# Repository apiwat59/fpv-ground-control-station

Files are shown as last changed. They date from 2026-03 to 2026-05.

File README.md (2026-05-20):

# Ground Control Station 'HALYT'

Ground Control Station 'HALYT' สำหรับ FPV drones เป็น modular system ที่รองรับการเปลี่ยน configuration ตามความเหมาะสมของงานและเงื่อนไขในการทำงาน

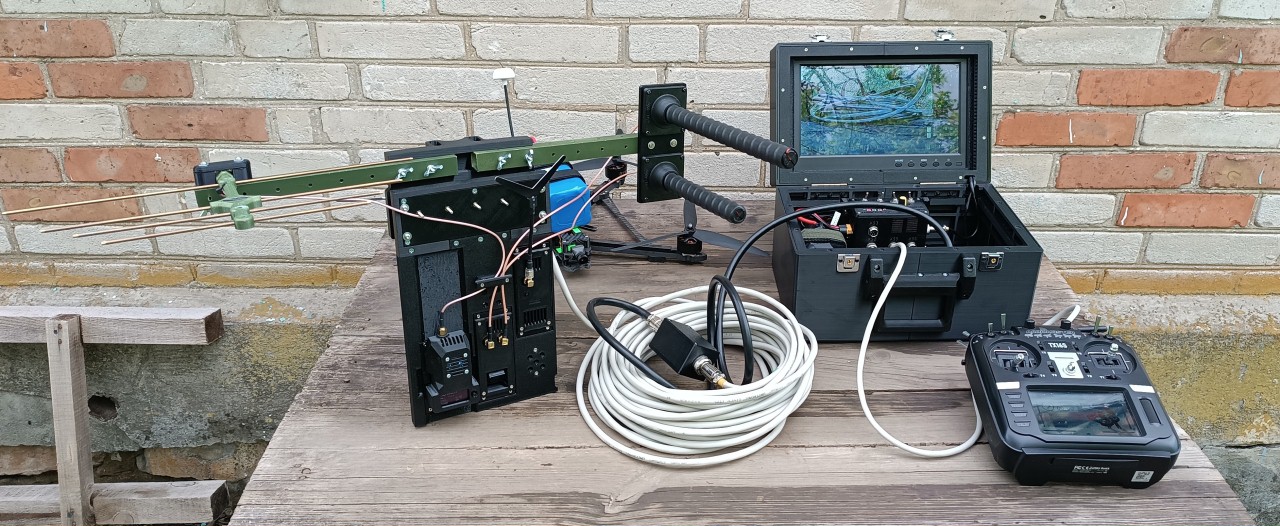
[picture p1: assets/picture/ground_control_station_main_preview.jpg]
General view of GCS 'HALYT'


สถาปัตยกรรมของสถานีตั้งอยู่บนหลักการของการแยกส่วนการทำงานของ system components ออกจากกัน และอนุญาตให้เพิ่ม functional expansion ได้โดยการรวม modules เพิ่มเติมโดยไม่ต้องเปลี่ยนโครงสร้างพื้นฐาน

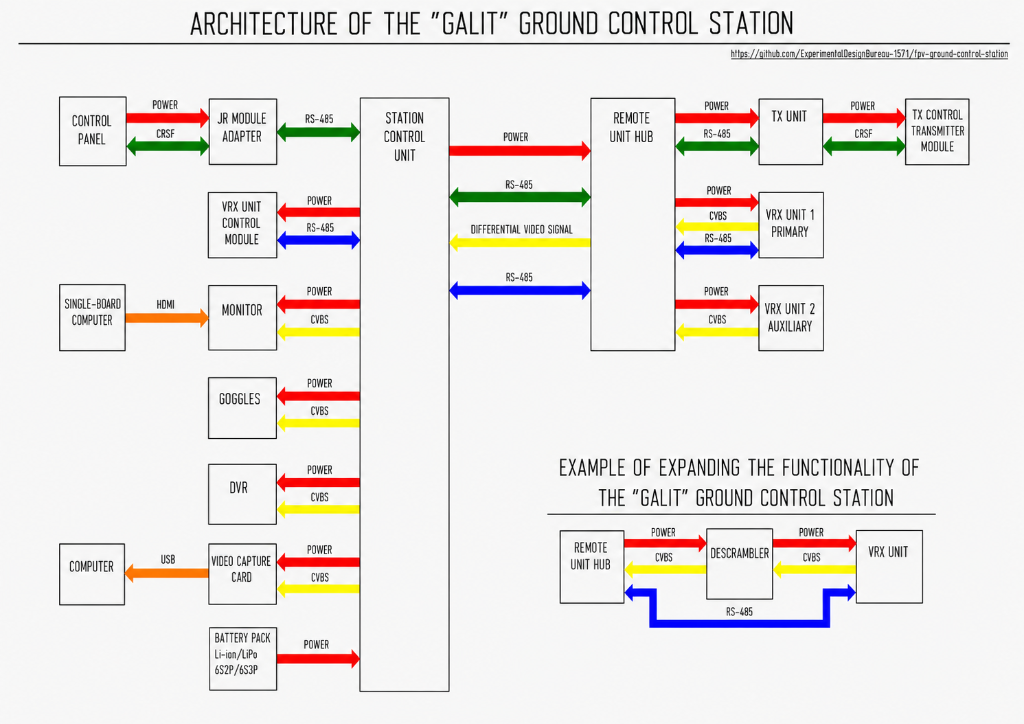
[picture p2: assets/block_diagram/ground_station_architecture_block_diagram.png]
GCS 'HALYT' Architecture


ระบบนี้ได้รับการพัฒนาขึ้นโดยคำนึงถึงประสบการณ์การรบจริงของเรา, ความพร้อมใช้งานของ components, การสนับสนุนผู้ผลิตในประเทศอย่างสูงสุด และความเป็นไปได้สำหรับเจ้าหน้าที่ด้านเทคนิคในการทำซ้ำแบบในโรงเวิร์กชอปภาคสนามทางการทหาร พลเรือน หรืออาสาสมัครที่มีอุปกรณ์ระดับปานกลาง

แนะนำให้ทำตามลำดับขั้นตอนด้านล่างนี้สำหรับการผลิตและการประกอบระบบ:

1.	**[Universal case and station body](Universal_case_and_station_body/)**
2.	**[Station control unit](Station_control_unit/)**
3.	**[Monitor modernization](Monitor_modernization/)**
4.	**[Remote unit](Remote_unit/)**
5.	**[VRX blocks](VRX_blocks/)**
6.	**[Control_subsystem](Control_subsystem/)**
7.	**[Cables](Cables/)**

## Video Guide for Manufacturing and Assembling GCS 'HALYT'

GCS HALYT — Full assembly video guide (https://www.youtube.com/watch?v=9ohl-sQVgZU)

*คลิกที่รูปภาพเพื่อรับชมวิดีโอบน YouTube*

เมื่อปฏิบัติตามคู่มือการผลิตและขั้นตอนปฏิบัติในการทำงาน ผลิตภัณฑ์ที่สมบูรณ์จะให้ระดับความแข็งแรงทางกล (mechanical strength), maintainability และคุณลักษณะการทำงานที่เทียบได้กับรุ่นที่ผลิตเพื่อการพาณิชย์ในคลาสเดียวกัน ภาพรวมทั่วไปของ Ground Control Station 'HALYT' แสดงอยู่ในภาพถ่าย

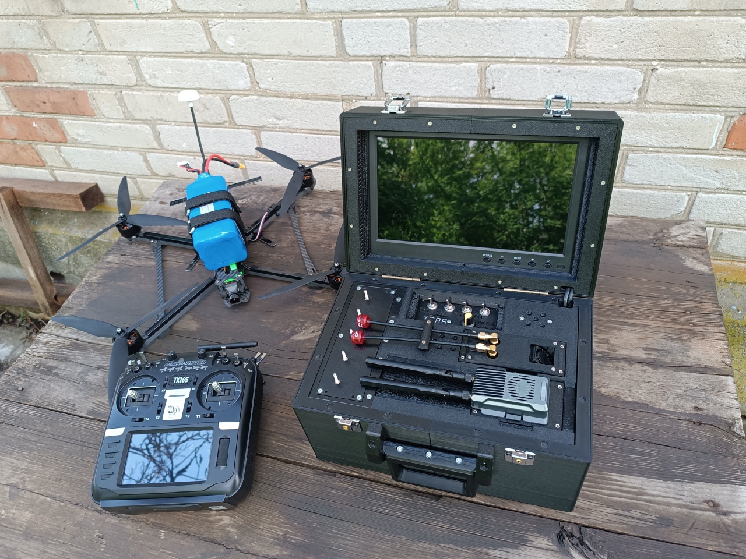
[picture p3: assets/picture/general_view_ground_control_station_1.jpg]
General view of GCS 'HALYT'
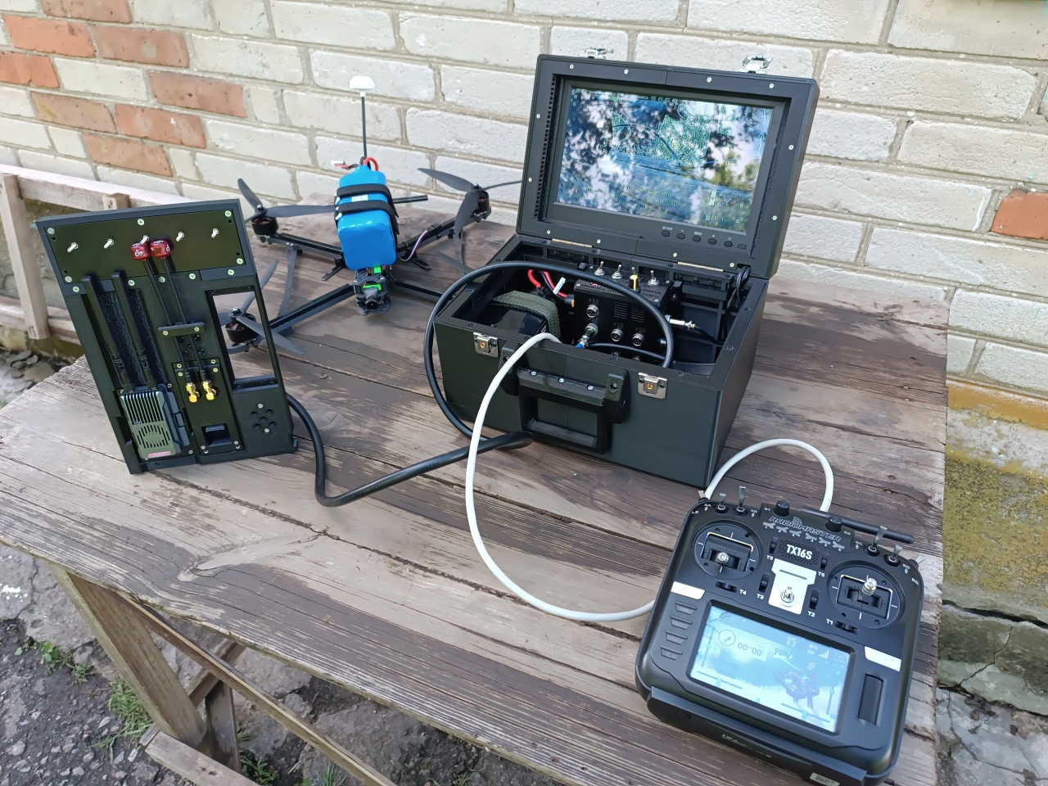
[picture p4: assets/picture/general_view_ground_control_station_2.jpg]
General view of GCS 'HALYT'
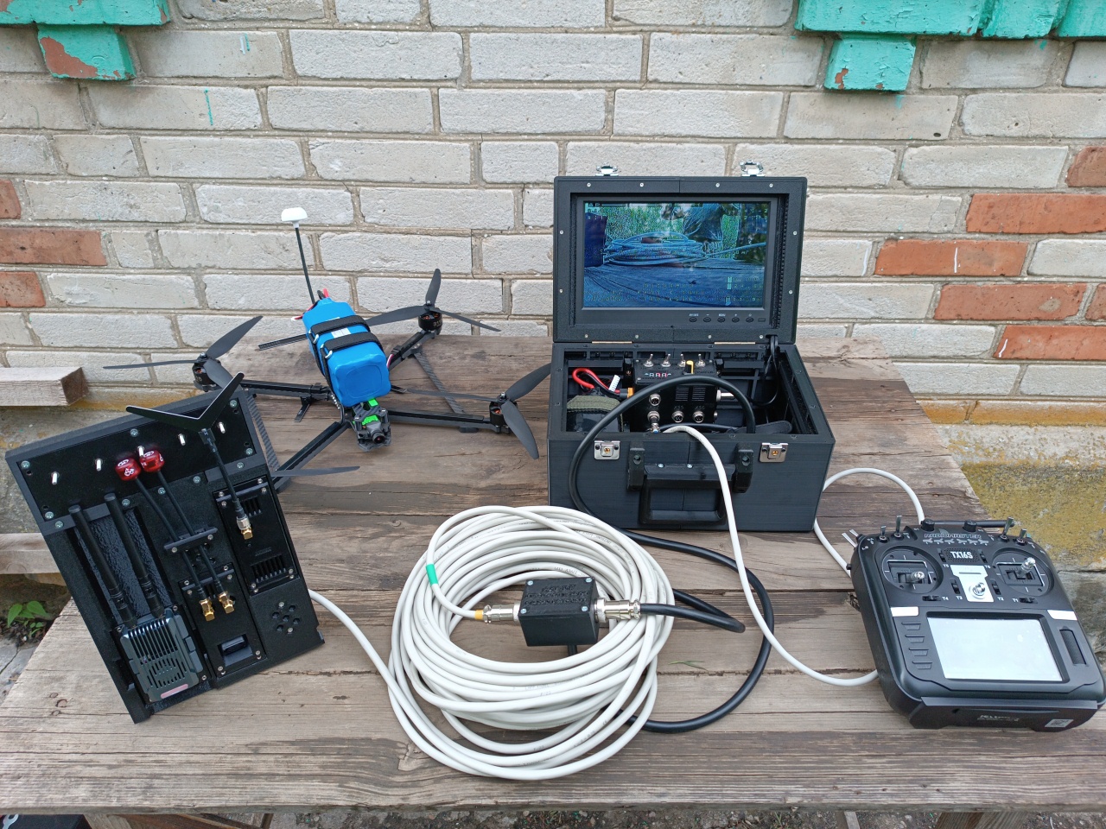
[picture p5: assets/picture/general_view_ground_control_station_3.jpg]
General view of GCS 'HALYT'
  

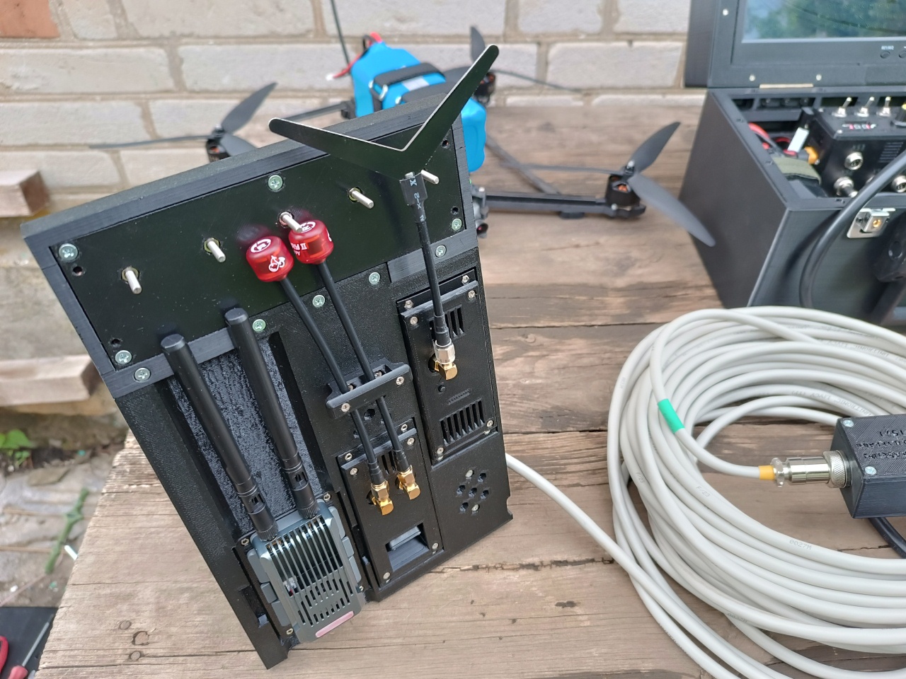
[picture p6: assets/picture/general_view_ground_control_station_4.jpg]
General view of GCS 'HALYT'
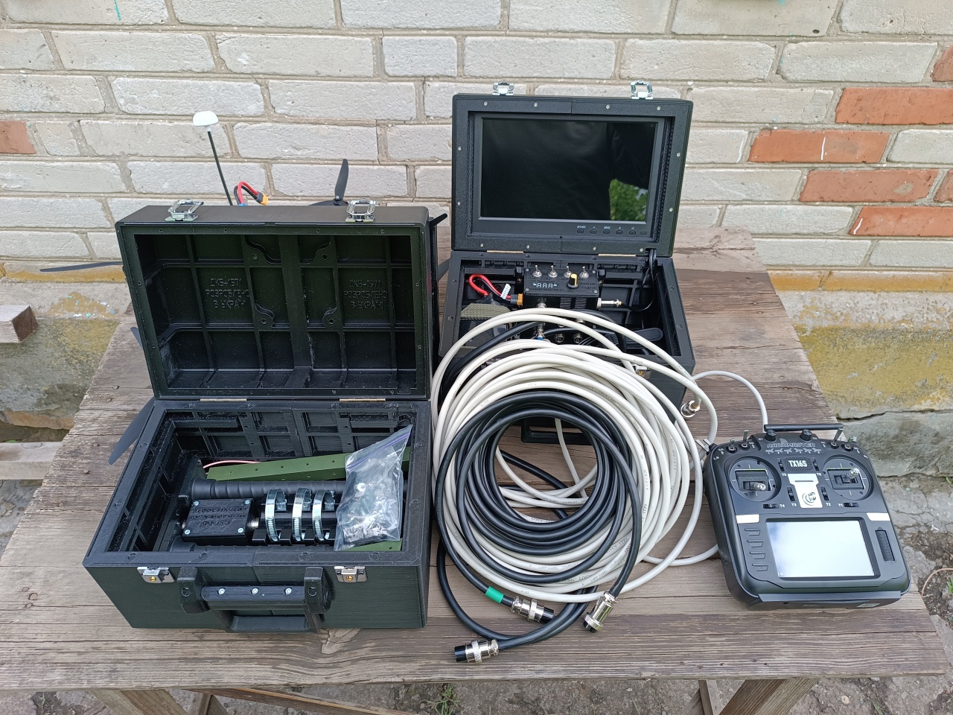
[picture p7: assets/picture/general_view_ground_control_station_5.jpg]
General view of GCS 'HALYT'
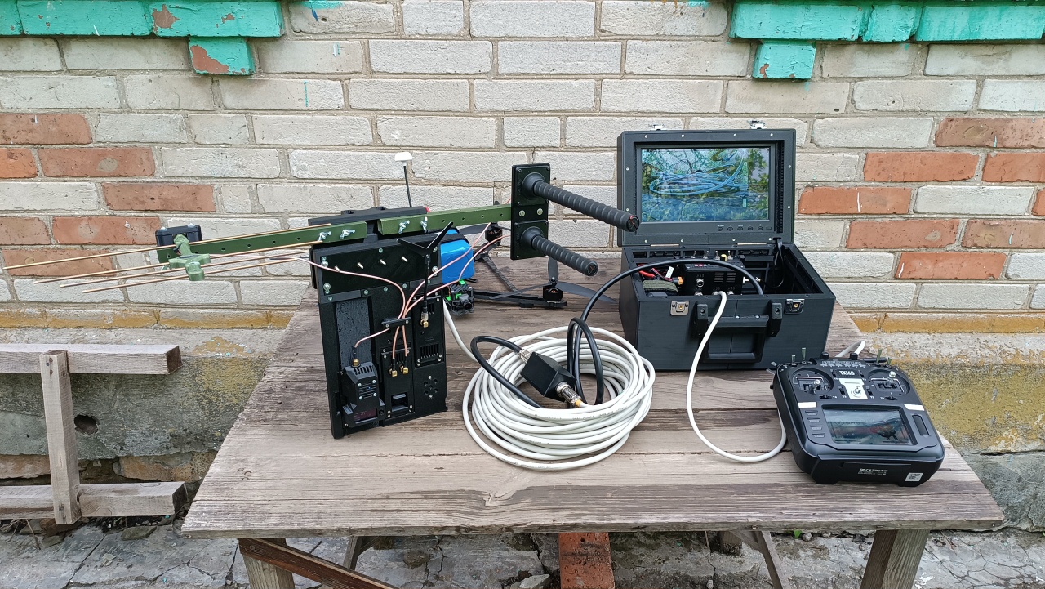
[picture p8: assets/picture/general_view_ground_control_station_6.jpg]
General view of GCS 'HALYT'
  

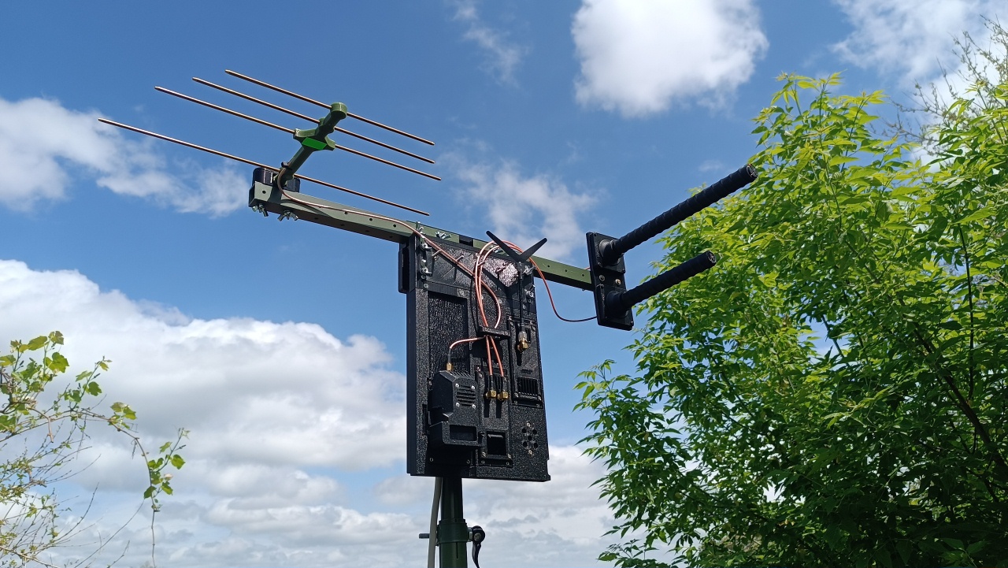
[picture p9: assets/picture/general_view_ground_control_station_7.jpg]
General view of GCS 'HALYT'
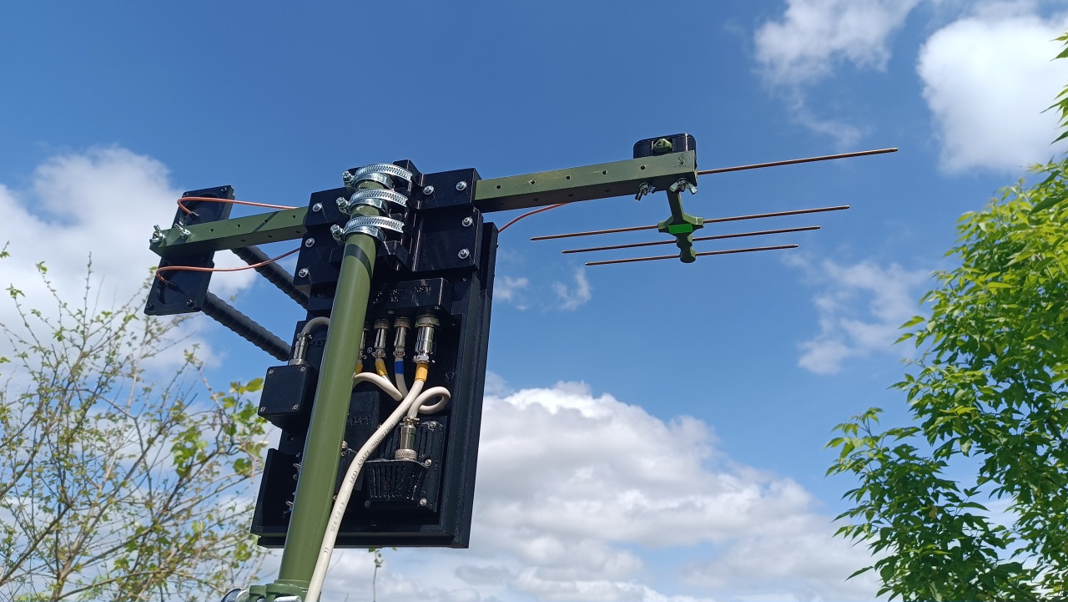
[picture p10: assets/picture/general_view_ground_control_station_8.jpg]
General view of GCS 'HALYT'
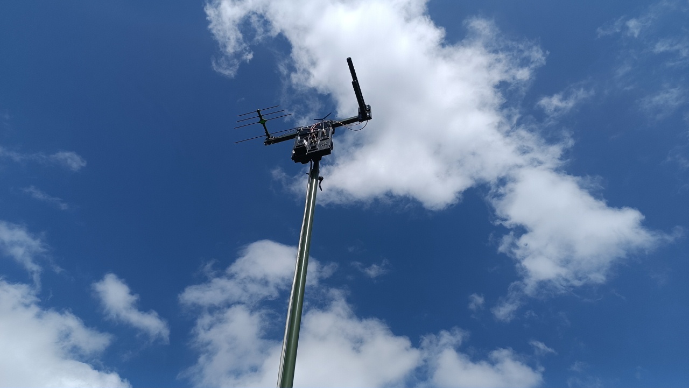
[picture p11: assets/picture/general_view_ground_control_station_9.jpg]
General view of GCS 'HALYT'
  

## License

การใช้ materials ใน repository นี้อยู่ภายใต้บังคับของ License Agreement ซึ่งมีข้อกำหนดหลักดังนี้:

- Materials จัดทำขึ้นเพื่อการใช้งานด้าน technical, educational, research หรือการใช้งานอื่นที่ไม่ใช่ในเชิงพาณิชย์เท่านั้น
- การผลิตผลิตภัณฑ์ตาม Materials ได้รับอนุญาตให้ทำได้เฉพาะการใช้งานที่ไม่ใช่ในเชิงพาณิชย์เท่านั้น โดยเฉพาะอย่างยิ่งเพื่อความต้องการในการป้องกันประเทศของยูเครน
- ห้ามใช้งาน materials การปรับปรุงแก้ไข หรือผลิตภัณฑ์ที่ผลิตขึ้นโดยอ้างอิงจาก materials ในเชิงพาณิชย์ทุกกรณี โดยไม่ได้รับความยินยอมเป็นลายลักษณ์อักษรแยกต่างหากจาก DKB-1571
- ไม่อนุญาตให้ทำการ Redistribution ของ materials และอนุญาตเฉพาะการแบ่งปัน links ไปยัง resources ทางการของ DKB-1571 เท่านั้น
- Materials ถูกจัดเตรียมให้ตามสภาพที่เป็นอยู่ ('as is') โดยที่ User ใช้งานโดยแบกรับความเสี่ยงด้วยตนเอง
- สิทธิ์ในทรัพย์สินทางปัญญาที่เป็นกรรมสิทธิ์แต่เพียงผู้เดียวของ Materials เป็นของ DKB-1571

โปรดตรวจสอบข้อตกลงสัญญาอนุญาตเวอร์ชันเต็มในไฟล์ `LICENSE.md` ของ repository นี้

---

โครงการนี้ถูกสร้างขึ้นโดยอิงจากประสบการณ์การรบจริงในการใช้งาน FPV systems

Engineer 'Trolleybus'  
Donetsk Oblast, Ukraine  
2026

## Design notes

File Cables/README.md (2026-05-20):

# Cables

ในการเชื่อมต่อ control unit เข้ากับ remote unit ของ station รวมถึงการเชื่อมต่ออุปกรณ์ peripheral เข้ากับพวกมัน จะใช้ cables ที่ทำจาก shielded multi-strand copper twisted pair

## Set 1 - Trunk

Set นี้ได้รับการออกแบบมาเพื่อเชื่อมต่อ control unit และ remote unit ของ station เข้าด้วยกัน โดยมาตรฐานของ trunk cable จะมีความยาว 2 meters และจัดเก็บไว้ใน station body ระหว่างการเคลื่อนย้าย ทั้งนี้ขึ้นอยู่กับลักษณะงาน set นี้สามารถเสริมด้วย trunk cables เพิ่มเติมได้ เช่น cable ขนาด 5-8 meters สำหรับใช้งานร่วมกับ repeater จาก shelter และ cable ขนาด 25-50 meters สำหรับการใช้งานแบบประจำที่ (stationary) จาก shelter

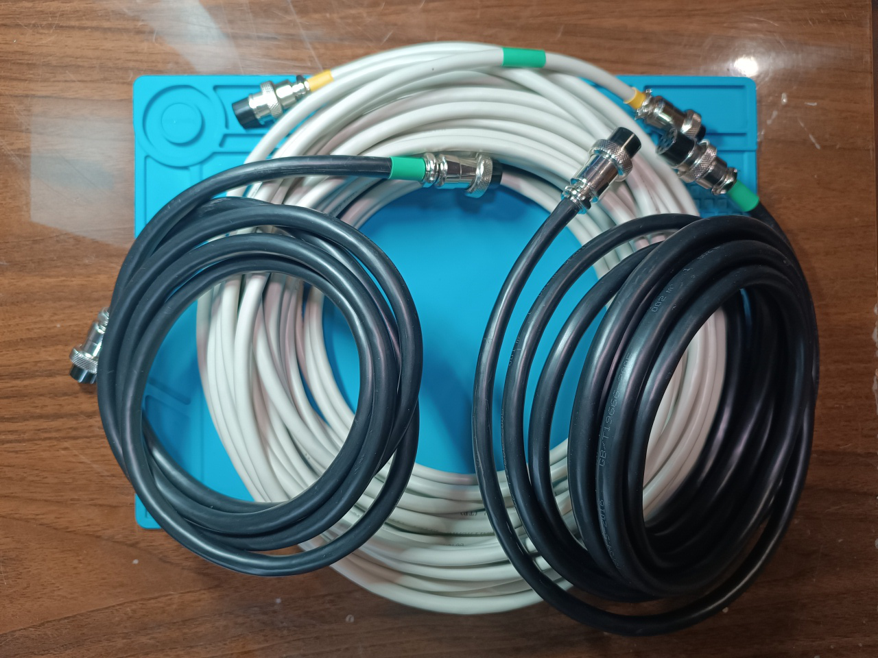
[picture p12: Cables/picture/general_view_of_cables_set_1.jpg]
General view of Set 1 cables


จุดเริ่มต้นของ standard trunk cable จะเชื่อมต่อกับ control unit และจุดสิ้นสุดจะเชื่อมต่อกับ remote unit hub ของ station

ในการเชื่อมต่อ standard trunk cable เข้ากับ additional cable จะใช้ cable connector โดยปลายของ standard trunk cable จะเสียบเข้ากับ port หนึ่งของ connector และจุดเริ่มต้นของ additional trunk cable จะเสียบเข้ากับ port ที่สอง จากนั้นปลายของ additional trunk cable จะเชื่อมต่อกับ remote unit hub ของ station ตามลำดับ

หากไม่มี connector ตัว additional trunk cable จะเชื่อมต่อโดยตรงกับ control unit แทน standard trunk cable

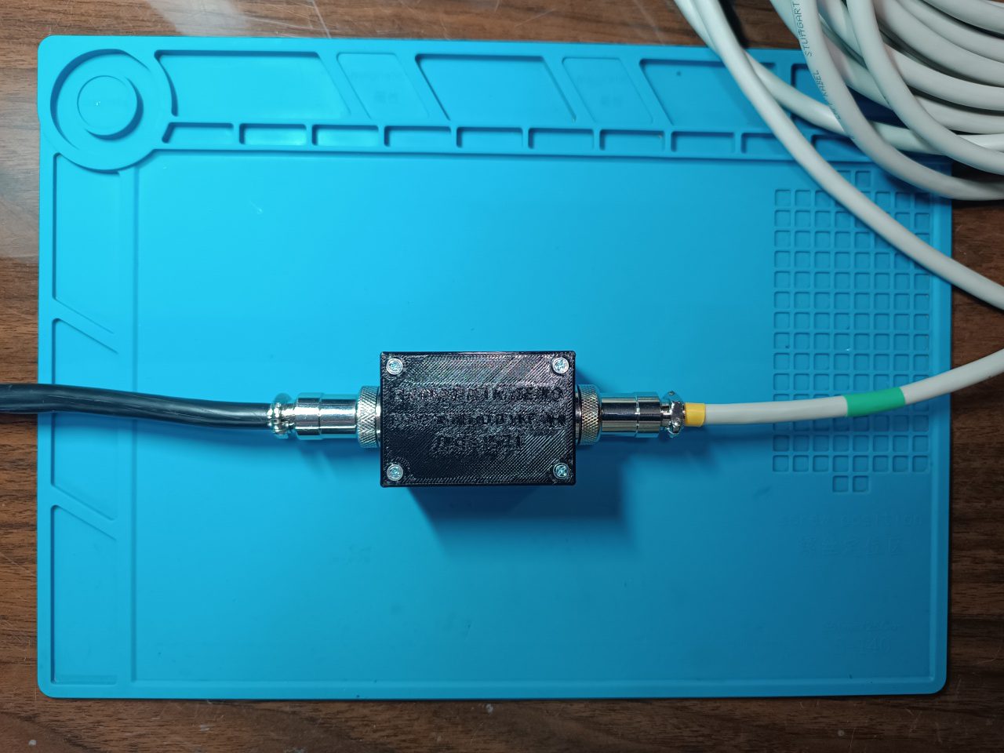
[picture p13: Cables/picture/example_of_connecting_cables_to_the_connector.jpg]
Example of connecting Set 1 cables using the cable connector


ในการผลิต trunk set สามารถใช้ cable types ต่อไปนี้ได้:
<ul>
<li>RVSP twisted pair 8x0.5mm² / 20AWG</li>
<li>RVSP twisted pair 8x0.3mm² / 22AWG</li>
<li>LAPP UNITRONIC LiYCY (TP) 4x2x0.5</li>
<li>LAPP UNITRONIC LiYCY (TP) 4x2x0.25</li>
</ul>

ความยาวของแนว trunk cable ขึ้นอยู่กับ cable type สำหรับ cables ที่มี cross-section ขนาด 0.5 mm² ความยาวสูงสุดของสายคือ 50 meters และสำหรับ cables ที่มี cross-section ขนาด 0.25-0.3 mm² ความยาวสูงสุดของสายคือ 25 meters

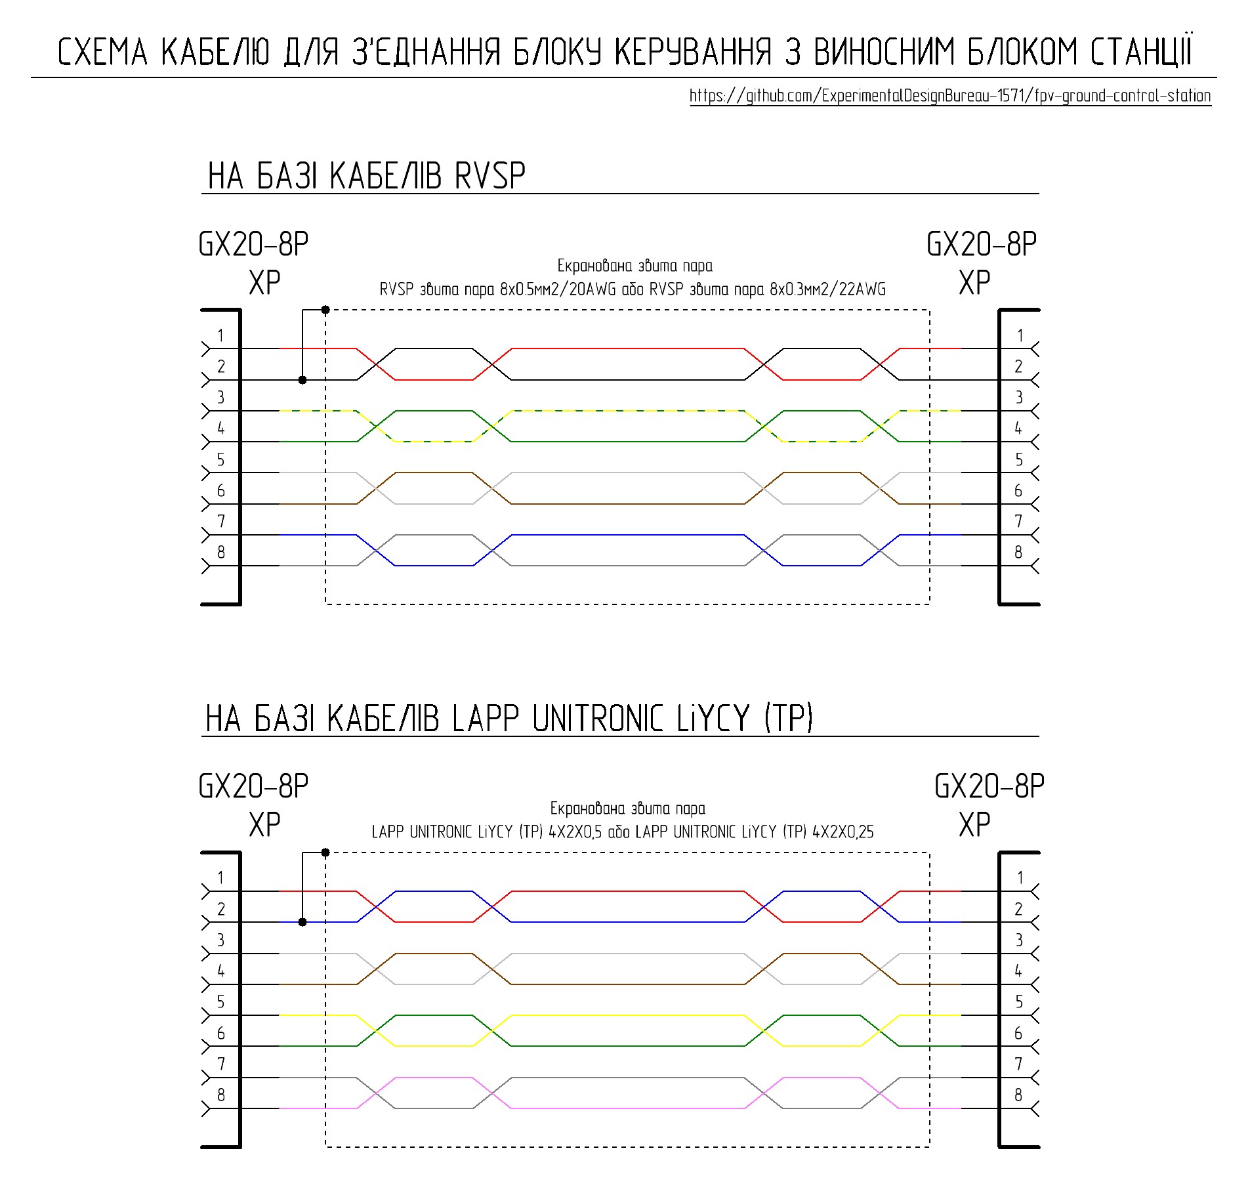
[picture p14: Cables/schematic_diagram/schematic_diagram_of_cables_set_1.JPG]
Schematic diagram of Set 1 cables


### Note!
<ul>
<li>ในการผลิต cables การเชื่อมต่อ cable shield เข้ากับสาย common (ground) บน connector จะทำเพียงด้านเดียวเท่านั้น เพื่อป้องกันไม่ให้เกิด ground loops</li>
<li>ด้านของ cable ที่เชื่อมต่อ shield เข้ากับสาย common จะเป็นจุดเริ่มต้น of cable โดยจุดเริ่มต้นของ cable จะถูกทำเครื่องหมายด้วย heat-shrink tubing</li>
<li>เมื่อใช้ cables ที่มี cross-section ขนาด 0.5 mm² ช่องทางเข้าของ connector housings จะต้องถูกตะไบหรือขยายขนาดด้วย needle file ให้มีขนาดเท่ากับเส้นผ่านศูนย์กลางของ cable ที่ใช้</li>
</ul>

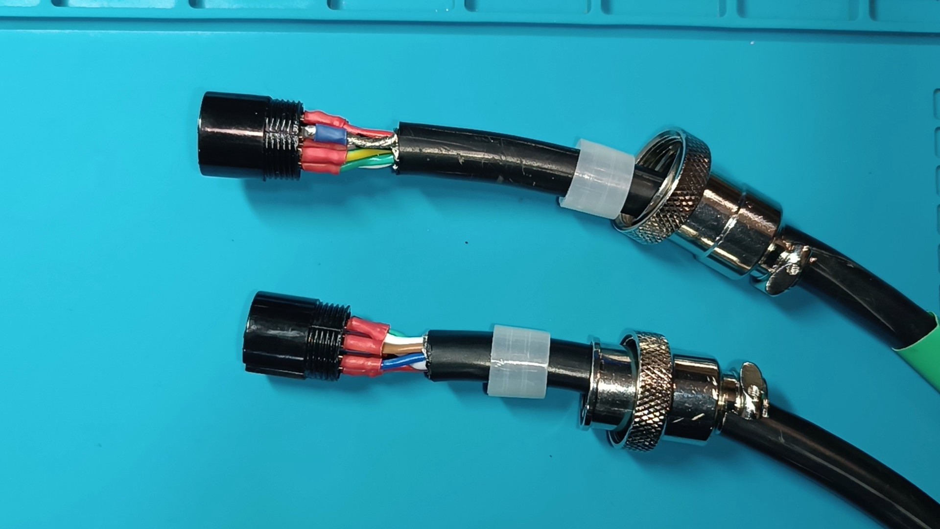
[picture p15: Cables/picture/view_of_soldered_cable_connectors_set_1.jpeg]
Soldering connectors on Set 1 cable


### List of required components for manufacturing one standard trunk cable

| Component name | Quantity | Note |
| :--- | :--- | :---: |
| RVSP twisted pair 8x0.5mm² / 20AWG or RVSP twisted pair 8x0.3mm² / 22AWG or LAPP UNITRONIC LiYCY (TP) 4x2x0.5 or LAPP UNITRONIC LiYCY (TP) 4x2x0.25 | 2 meters |  |
| Cable socket GX20-8 pin (female) | 2 pcs |  |

## Set 1 Cable Connector

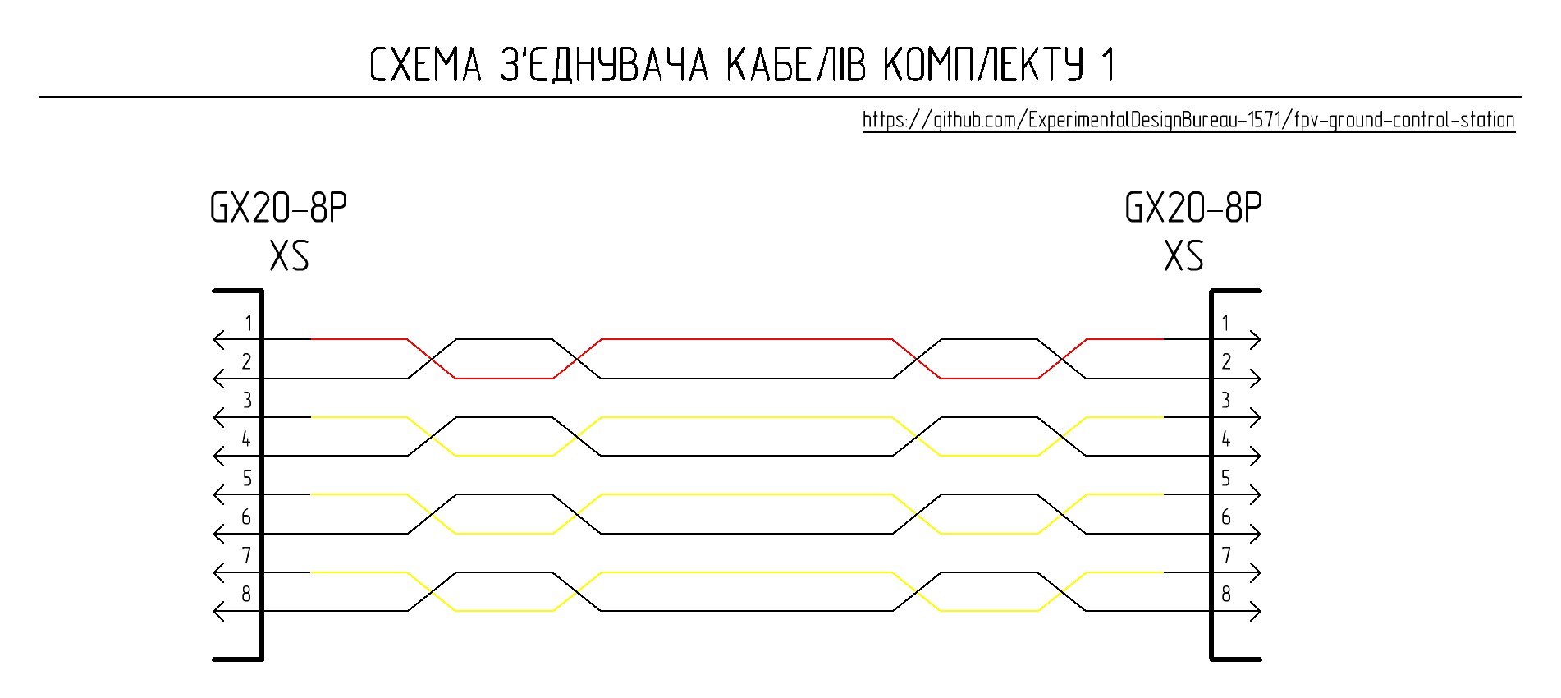
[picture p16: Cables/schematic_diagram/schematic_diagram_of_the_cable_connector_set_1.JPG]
Schematic diagram of the Set 1 cable connector


ในด้านการออกแบบ connector ถูกสร้างขึ้นใน enclosure ขนาดเล็กที่ประกอบด้วย sockets ซึ่งเชื่อมต่อสายเข้าด้วยกันตาม electrical schematic ที่เกี่ยวข้อง

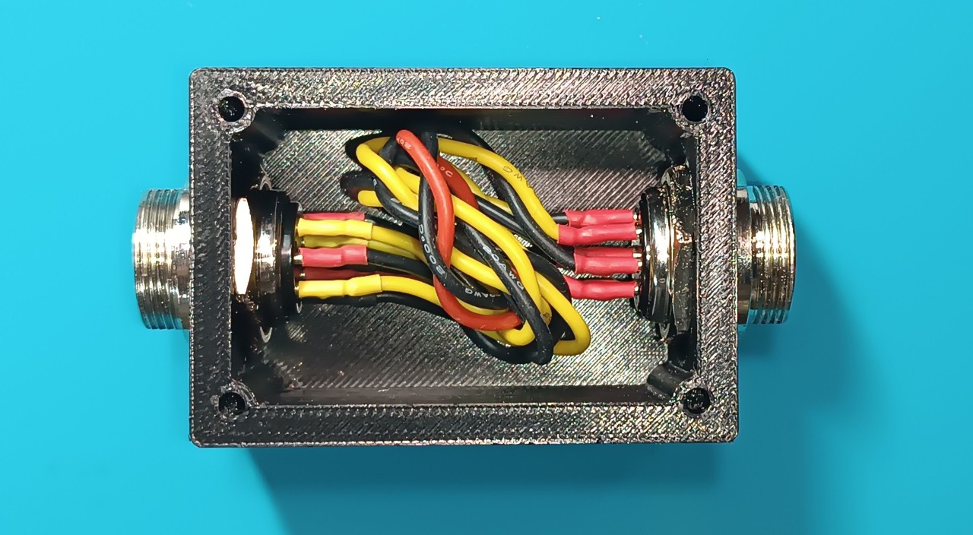
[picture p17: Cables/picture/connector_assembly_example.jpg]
Example of cable connector assembly


### List of required components for manufacturing one connector

| Component name | Quantity | Note |
| :--- | :--- | :---: |
| Panel-mount plug GX20-8 pin (male) | 2 pcs |  |
| Copper wire 20 AWG with silicone insulation, red | 110 mm  |  |
| Copper wire 20 AWG with silicone insulation, black | 440 mm  |  |
| Copper wire 20 AWG with silicone insulation, yellow | 330 mm  |  |
| Screw M3x40 DIN 965 | 4 pcs |  |
| Nut M3 DIN 934 | 4 pcs  |  |
| Part 1 - 3D printed | 1 pc  |  |
| Part 2 - 3D printed | 1 pc |  |

## Set 2 - Peripheral

Set นี้ออกแบบมาสำหรับเชื่อมต่ออุปกรณ์ peripheral เข้ากับ control unit และ remote unit ของ station ประกอบด้วย:
<ul>
<li>cables for connecting VRX blocks (ใช้ yellow heat-shrink tubing)</li>
<li>control subsystem cables (ใช้ blue heat-shrink tubing)</li>
</ul>

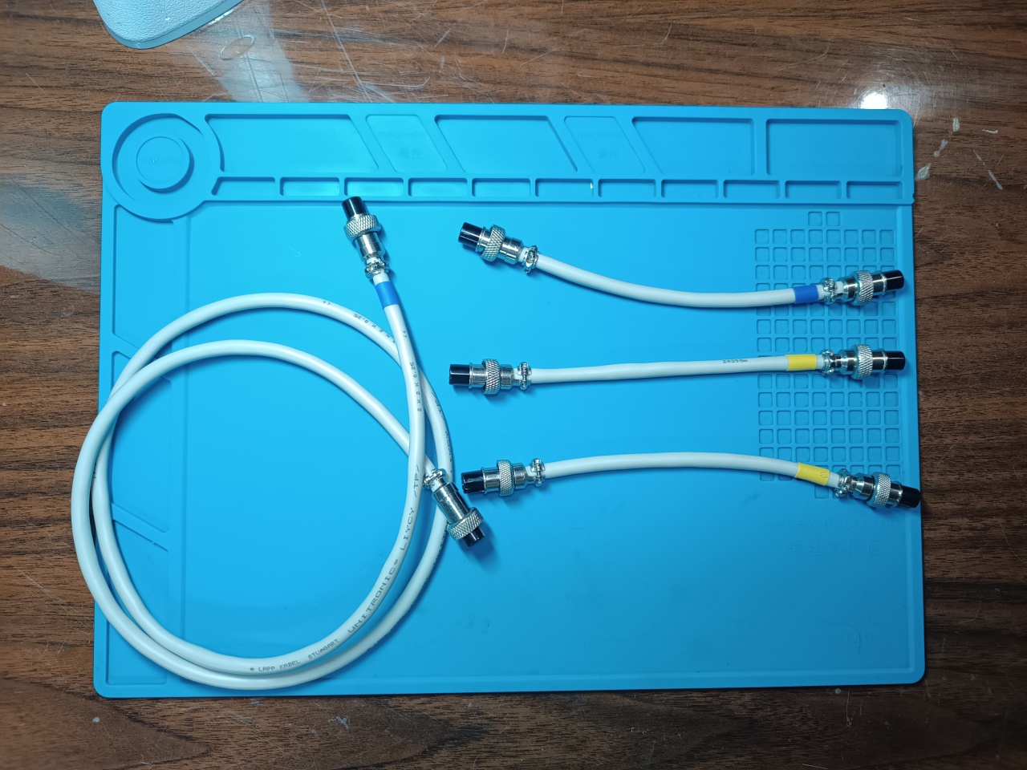
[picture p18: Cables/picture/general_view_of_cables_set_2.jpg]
General view of Set 2 cables


## Cables for Connecting VRX Blocks

ทั้งนี้ขึ้นอยู่กับ station configuration ซึ่งสามารถเลือกใช้ cable options ได้สองแบบ แตกต่างกันที่ความสามารถในการส่งสัญญาณควบคุมไปยัง VRX block หากควบคุม VRX block แบบ manual หรือผ่าน ELRS Backpack จะใช้สายทางเลือกแรก (first option cable) หากควบคุมผ่าน switching lines ของ ground station จะใช้สายทางเลือกที่สอง (second option cable) จุดเริ่มต้นของ cable เชื่อมต่อกับ remote unit hub และจุดสิ้นสุดของ cable เชื่อมต่อกับ VRX block

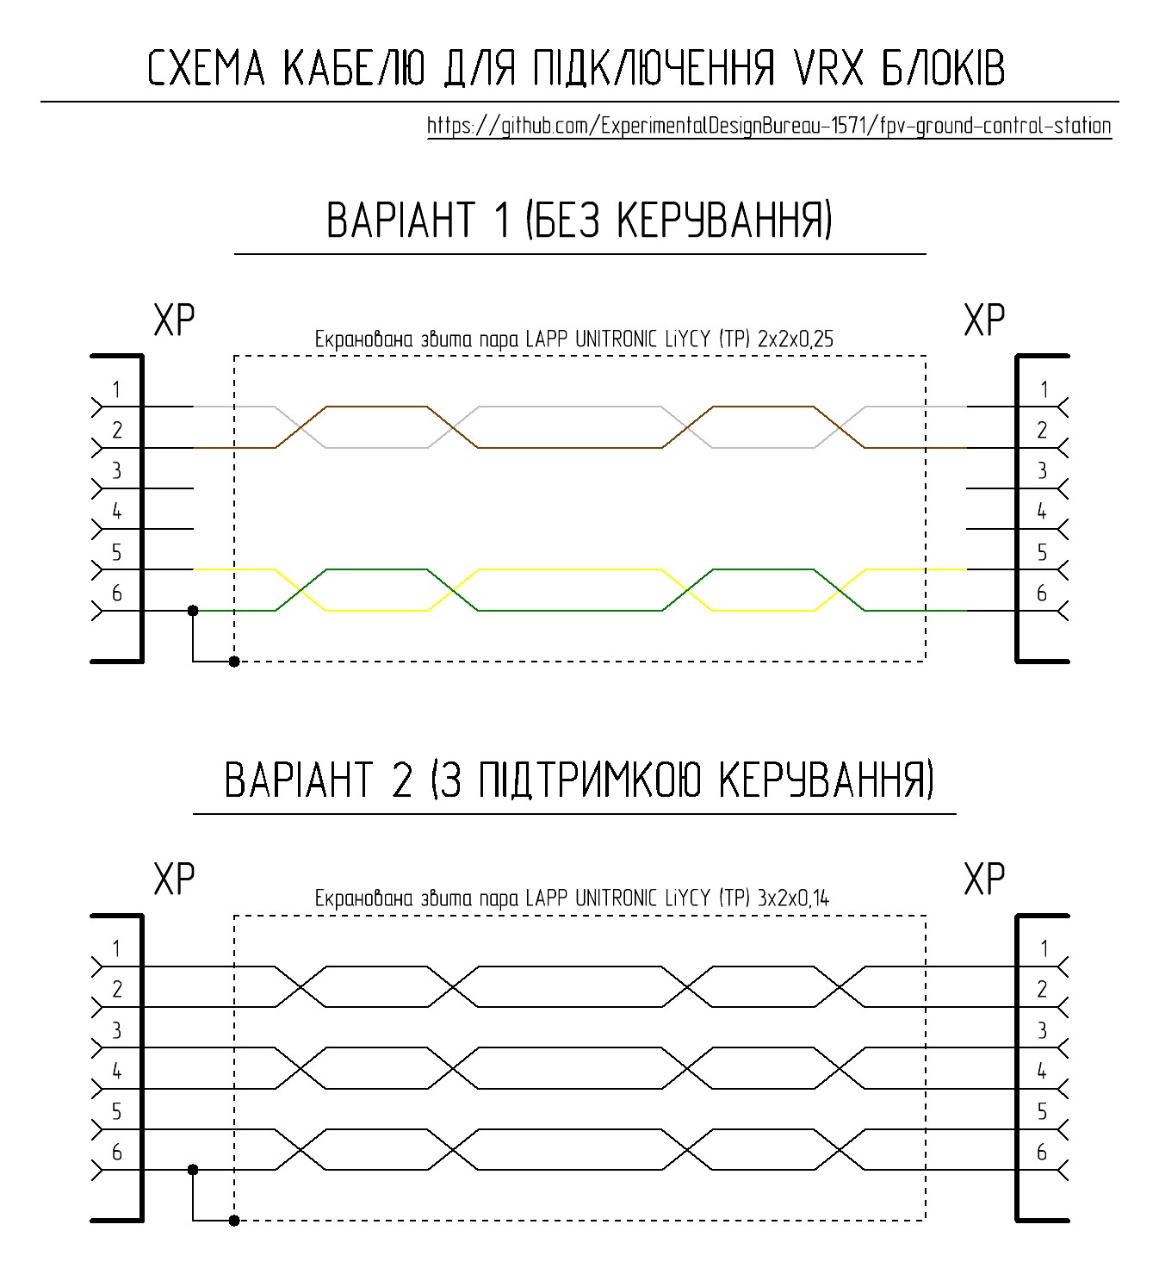
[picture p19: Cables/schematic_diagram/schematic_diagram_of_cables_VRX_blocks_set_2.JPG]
Schematic diagram of cables for connecting VRX blocks of Set 2


### Note!
<ul>
<li>ในการผลิต cables การเชื่อมต่อ cable shield เข้ากับสาย common (ground) บน connector จะทำเพียงด้านเดียวเท่านั้น เพื่อป้องกันไม่ให้เกิด ground loops</li>
<li>ด้านของ cable ที่เชื่อมต่อ shield เข้ากับสาย common จะเป็นจุดเริ่มต้นของ cable โดยจุดเริ่มต้นของ cable จะถูกทำเครื่องหมายด้วย heat-shrink tubing ซึ่งสีของ tubing จะเป็นตัวบ่งบอกประเภทของ cable ด้วย (ใช้สีเหลืองสำหรับการเชื่อมต่อ VRX blocks)</li>
<li>ในการผลิต cables ช่องทางเข้าของ connector housings จะต้องถูกตะไบหรือขยายขนาดด้วย needle file ให้มีขนาดเท่ากับเส้นผ่านศูนย์กลางของ cable ที่ใช้</li>
</ul>

### List of required components for manufacturing one VRX block connection cable

| Component name | Quantity | Note |
| :--- | :--- | :---: |
| LAPP UNITRONIC LiYCY (TP) 2x2x0.25 or LAPP UNITRONIC LiYCY (TP) 3x2x0.14 | 120 mm |  |
| Cable socket GX12-6 pin (female) | 2 pcs |  |

## Control Subsystem Cables

cable ประเภทนี้ใช้เพื่อเชื่อมต่อ JR module สำหรับ remote controller (สายยาว) และ TX unit (สายสั้น) โดยจุดเริ่มต้นของ cable ที่เชื่อมต่อ JR module เข้ากับ station control unit จะเชื่อมต่อเข้ากับ control unit และปลายสายเชื่อมต่อกับ JR module สำหรับจุดเริ่มต้นของ cable ที่เชื่อมต่อ TX unit เข้ากับ remote unit hub จะเชื่อมต่อเข้ากับ hub และปลายสายเชื่อมต่อกับ TX unit

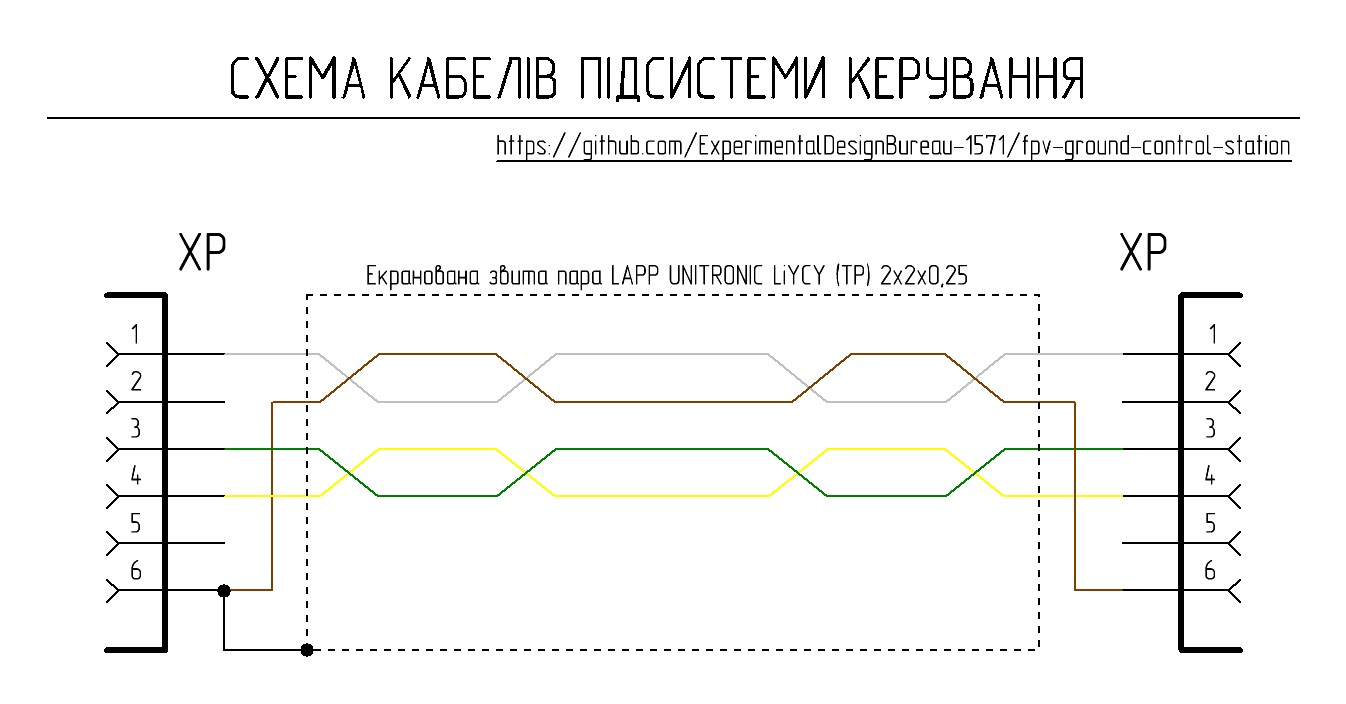
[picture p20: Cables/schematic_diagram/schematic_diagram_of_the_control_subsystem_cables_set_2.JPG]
Schematic diagram of the control subsystem cables of Set 2


### Note!
<ul>
<li>ในการผลิต cables การเชื่อมต่อ cable shield เข้ากับสาย common (ground) บน connector จะทำเพียงด้านเดียวเท่านั้น เพื่อป้องกันไม่ให้เกิด ground loops</li>
<li>ด้านของ cable ที่เชื่อมต่อ shield เข้ากับสาย common จะเป็นจุดเริ่มต้นของ cable โดยจุดเริ่มต้นของ cable จะถูกทำเครื่องหมายด้วย heat-shrink tubing ซึ่งสีของ tubing จะเป็นตัวบ่งบอกประเภทของ cable ด้วย (ใช้สีน้ำเงินสำหรับ control subsystem cables)</li>
<li>ในการผลิต cables ช่องทางเข้าของ connector housings จะต้องถูกตะไบหรือขยายขนาดด้วย needle file ให้มีขนาดเท่ากับเส้นผ่านศูนย์กลางของ cable ที่ใช้</li>
</ul>

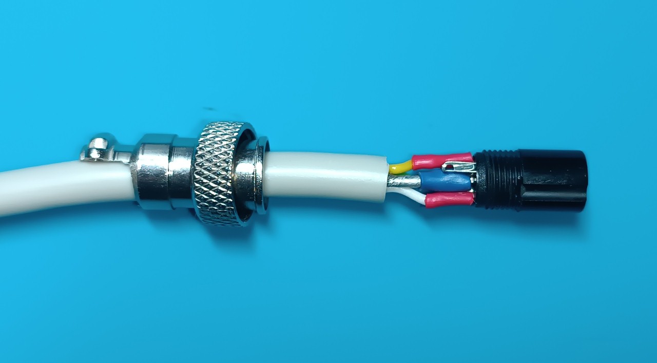
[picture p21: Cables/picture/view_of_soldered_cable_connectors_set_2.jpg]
Soldering connector on Set 2 cable


### List of required components for manufacturing one set of control subsystem cables

| Component name | Quantity | Note |
| :--- | :--- | :---: |
| LAPP UNITRONIC LiYCY (TP) 2x2x0.25 | 1120 mm | 1000 mm - long cable, 120 mm - short cable |
| Cable socket GX12-6 pin (female) | 4 pcs |  |

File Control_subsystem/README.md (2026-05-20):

# Control_subsystem

Control subsystem ให้บริการแลกเปลี่ยนข้อมูลแบบสองทิศทาง (two-way data exchange) ผ่าน switching lines ของ ground control station โดยใช้มาตรฐาน RS-485 ระหว่าง operator's control panel และ control transmitter ที่ติดตั้งอยู่ใน remote unit ของ ground control station

Control subsystem ประกอบด้วย:
- JR_module_adapter (ทางฝั่ง control panel)
- TX_unit (ทางฝั่ง remote unit)

## Brief Technical Specifications

| Parameter | Value | Note |
|---|---|---|
| Control protocol | CRSF | ผ่าน S.Port |
| Transmission interface | Differential signal ของมาตรฐาน RS-485 | Noise-immune, long lines |
| Data transmission channel | Switching lines ของ ground control station | ความยาวสูงสุดขึ้นอยู่กับประเภทของ cable |
| Operating mode | Two-way | Control + telemetry |
| JR module adapter power supply | 5–8.4 V | จาก control panel |
| TX unit power supply | จาก remote unit hub | ผ่าน XS2 |
| Control transmitter TX module power supply | 8V | จาก TX unit |
| TX unit output voltage via XS3 connector | 8V | กระแสต่อเนื่องสูงสุด 2A |
| Cooling | Passive | Heatsinks + ช่องระบายอากาศ |
| Shielding | Partial | |

## Operating Principle and Architecture

สัญญาณควบคุมจาก control panel จะถูกส่งไปยัง JR_module_adapter ซึ่งจะถูกแปลงเป็น differential signal ของมาตรฐาน RS-485 จากนั้นสัญญาณจะถูกส่งผ่าน switching lines ของ ground control station ไปยัง TX_unit ซึ่งจะเกิดการแปลงสัญญาณกลับ (reverse conversion) เป็นสัญญาณโปรโตคอล CRSF ก่อนที่จะส่งต่อไปยัง control transmitter สำหรับช่องสัญญาณขากลับ (telemetry) จะทำงานในลักษณะเดียวกันแต่ในทิศทางตรงกันข้าม

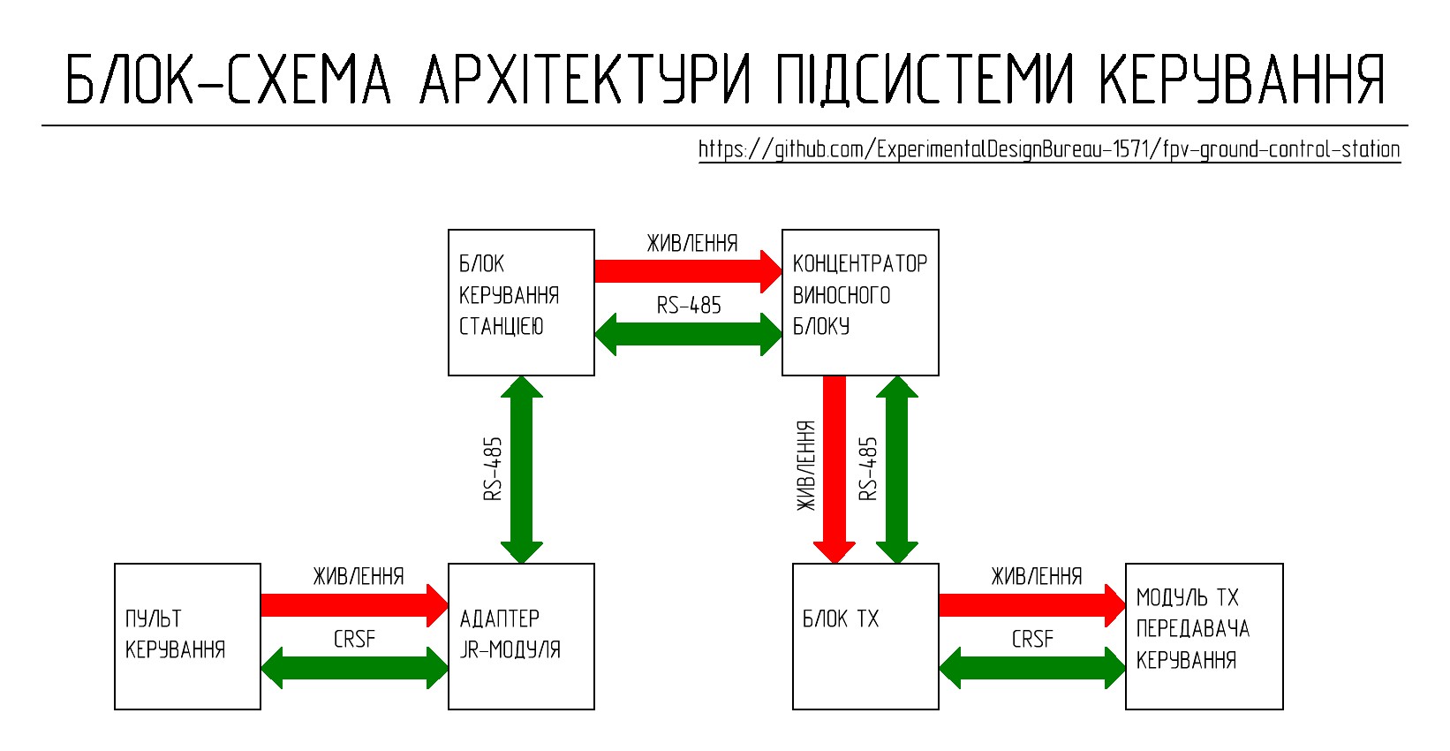
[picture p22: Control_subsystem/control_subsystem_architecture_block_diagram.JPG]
Block diagram of the control subsystem architecture


รายละเอียดการออกแบบและพัฒนาสำหรับแต่ละอุปกรณ์ของ control subsystem แสดงอยู่ในส่วนต่างๆ ดังนี้:

* **[JR_module_adapter](JR_module_adapter/)**
* **[TX_unit](TX_unit/)**

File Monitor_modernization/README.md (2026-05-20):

# Monitor Modernization

universal monitor ขนาดหน้าจอ 10.1 นิ้ว ถูกนำมาใช้งานเป็นอุปกรณ์แสดงผลมาตรฐานใน ground station การใช้ monitor ประเภทนี้เหมาะสมเนื่องจากความแพร่หลายในท้องตลาด ทั้งเรื่องจำนวนสินค้าและราคา รวมถึงความลงตัวของคุณลักษณะเฉพาะทางเทคนิค มีรุ่นที่รองรับทั้ง analog video input และช่องสัญญาณ input เพิ่มเติมอื่นๆ รวมถึงดิจิทัล HDMI input การใช้ monitor ที่มีช่องสัญญาณดิจิทัล HDMI video input เพิ่มเติมใน ground station จะช่วยขยายขอบเขตการใช้งานให้หลากหลายขึ้น ตัวอย่างเช่น สามารถเชื่อมต่อ modules อย่าง Walksnail Avatar VRX และ Walksnail Ascent VRX หรือ single-board computers อย่าง Raspberry Pi เข้ากับ monitor ได้โดยตรง

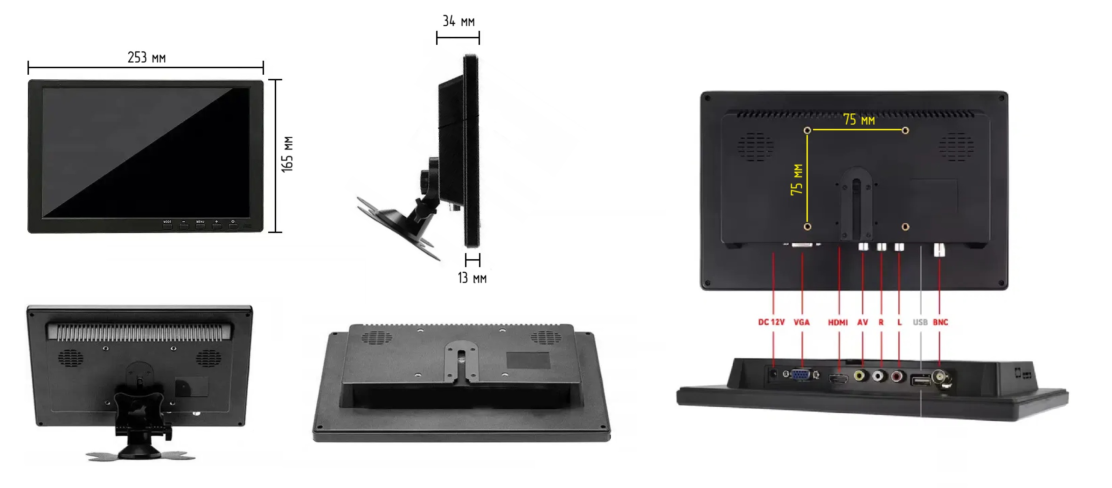
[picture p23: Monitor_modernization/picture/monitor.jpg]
General view of the monitor


monitor รุ่นนี้มีโหมด "blue screen" ที่จะทำงานเมื่อไม่มีสัญญาณวิดีโอบน active video input หรือเมื่อสัญญาณมีความผิดเพี้ยนไปอย่างมาก (significant distortion) ซึ่งเมื่อใช้ดิจิทัล HDMI video input โหมดนี้จะไม่มีผลใดๆ แต่เมื่อใช้ analog video input ความสามารถในการมองเห็นภาพผ่านสัญญาณรบกวน (noise) ถือเป็นเรื่องที่สำคัญอย่างยิ่ง

## Monitor Modernization - Theoretical Background

ปัญหา "blue screen" สามารถแก้ไขได้โดยการทำ modernization เล็กน้อยกับตัว monitor ซึ่งประกอบด้วยการประมวลผลสัญญาณวิดีโอเพิ่มเติมด้วย AT7456E chip เพื่อลดความซับซ้อนในขั้นตอนการดำเนินการให้มากที่สุด จึงเลือกใช้ flight controller ซึ่งได้รับการติดตั้งชิปตัวนี้พร้อมกับวงจรสนับสนุนอื่นๆ มาเรียบร้อยแล้ว ความเหมาะสมในการเลือกใช้ flight controller ยังมาจากการที่สามารถจัดหาได้ง่ายในภาคสนามหรือเวิร์กช็อปทั่วไป

หลักการทำงาน:
สัญญาณ output จากตัวรับสัญญาณวิดีโอ (video receiver) จะถูกประมวลผลโดย AT7456E chip ซึ่งชิป AT7456E จะช่วยคืนค่าและรักษาเสถียรภาพของการซิงโครไนซ์สัญญาณ (stabilizes synchronization) ทำให้เกิดสัญญาณ composite video signal ที่ถูกต้องที่ฝั่ง output แม้ว่าจะมีสัญญาณรบกวน (interference) ในระดับที่สูงมากก็ตาม

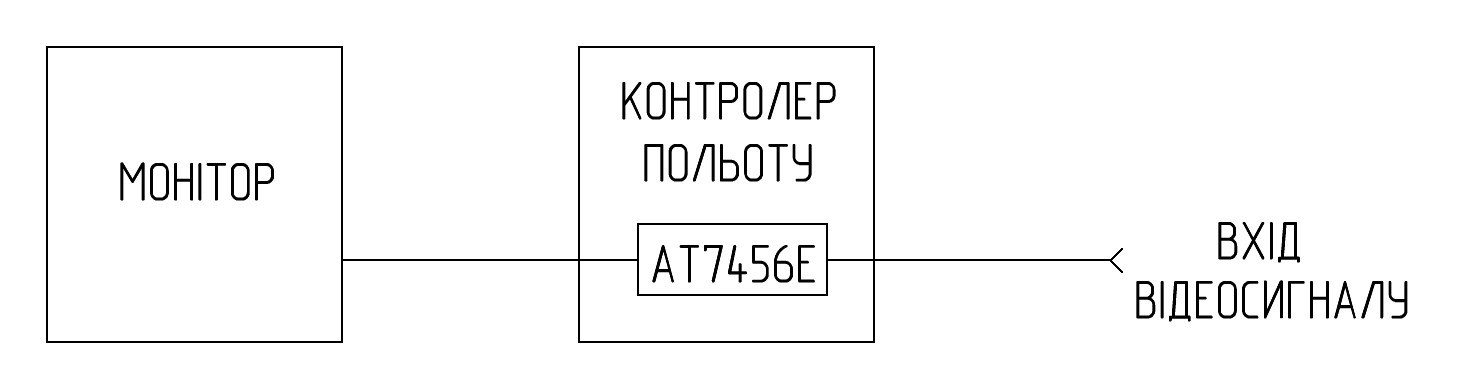
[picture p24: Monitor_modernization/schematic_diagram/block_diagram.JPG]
Block diagram


สำหรับตัว monitor แล้ว สัญญาณในลักษณะนี้จะดูเป็นสัญญาณที่ "ถูกต้อง" เสมอ ดังนั้นแม้ว่าภาพจาก drone จะเต็มไปด้วย noise หรือเกือบจะหายไปทั้งหมด monitor ก็จะไม่ตัดเข้าสู่โหมด "blue screen"

ผลลัพธ์: เรายังคงสามารถเห็นภาพได้จนถึงช่วงสุดท้ายโดยที่ monitor ไม่เปลี่ยนเข้าสู่โหมด "blue screen" ซึ่งมีความสำคัญอย่างวิกฤตเมื่อเกิดสัญญาณรบกวนที่รุนแรง

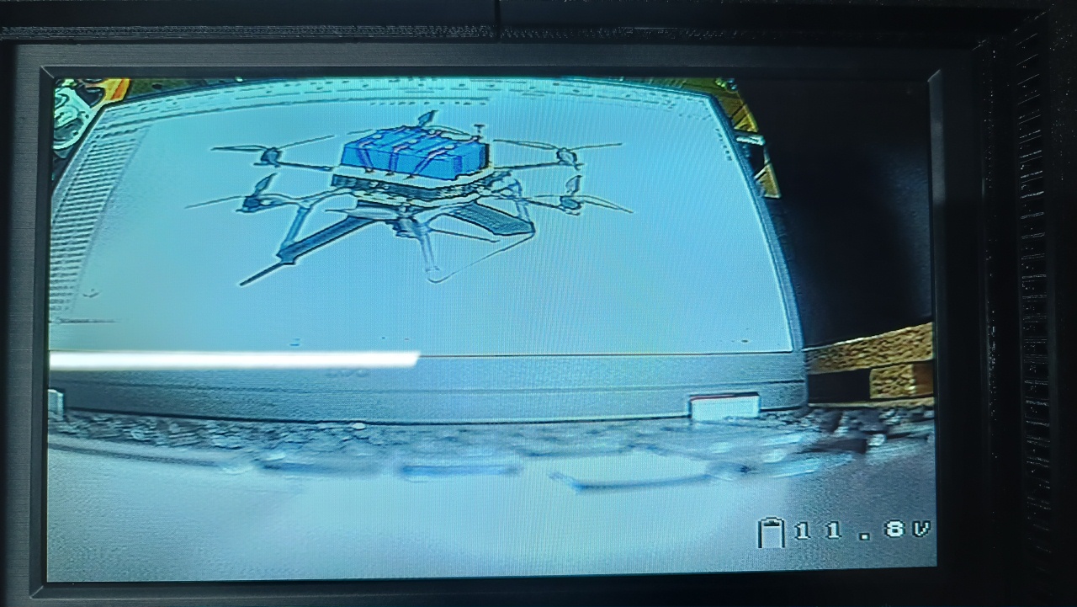
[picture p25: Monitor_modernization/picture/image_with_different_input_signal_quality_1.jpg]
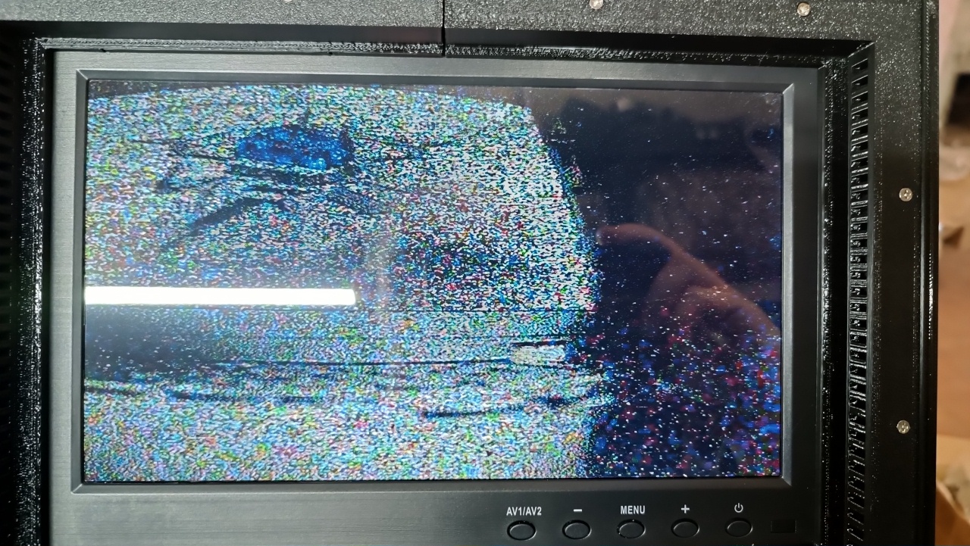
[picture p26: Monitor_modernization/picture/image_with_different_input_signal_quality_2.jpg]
 
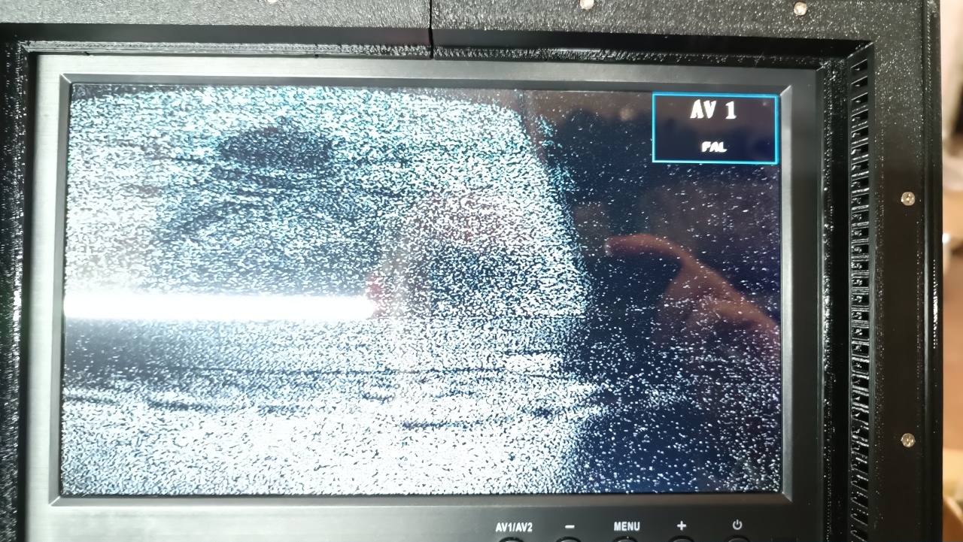
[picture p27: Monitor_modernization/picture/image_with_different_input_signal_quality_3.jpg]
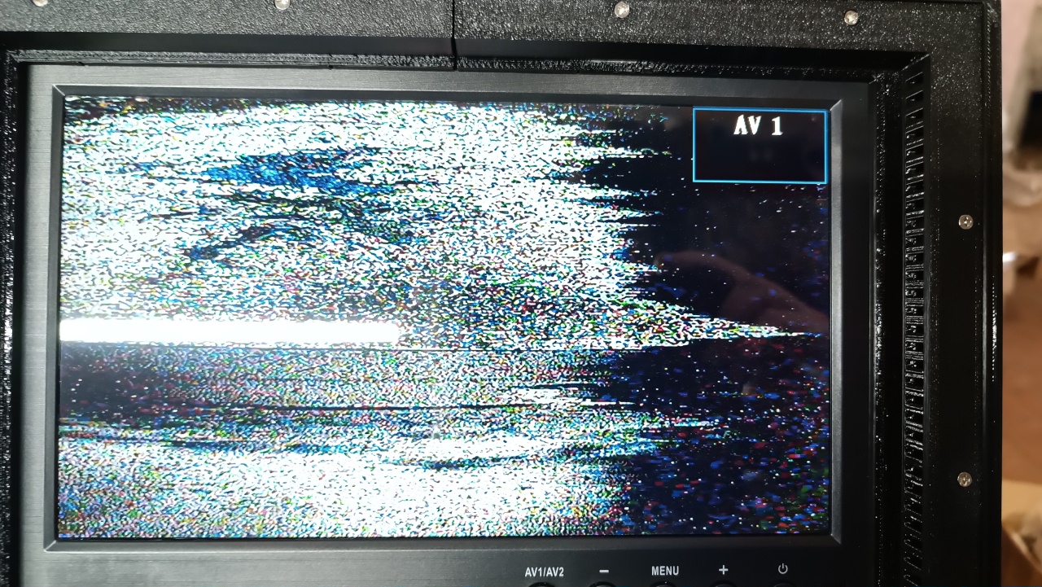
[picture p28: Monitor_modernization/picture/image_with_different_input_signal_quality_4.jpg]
 
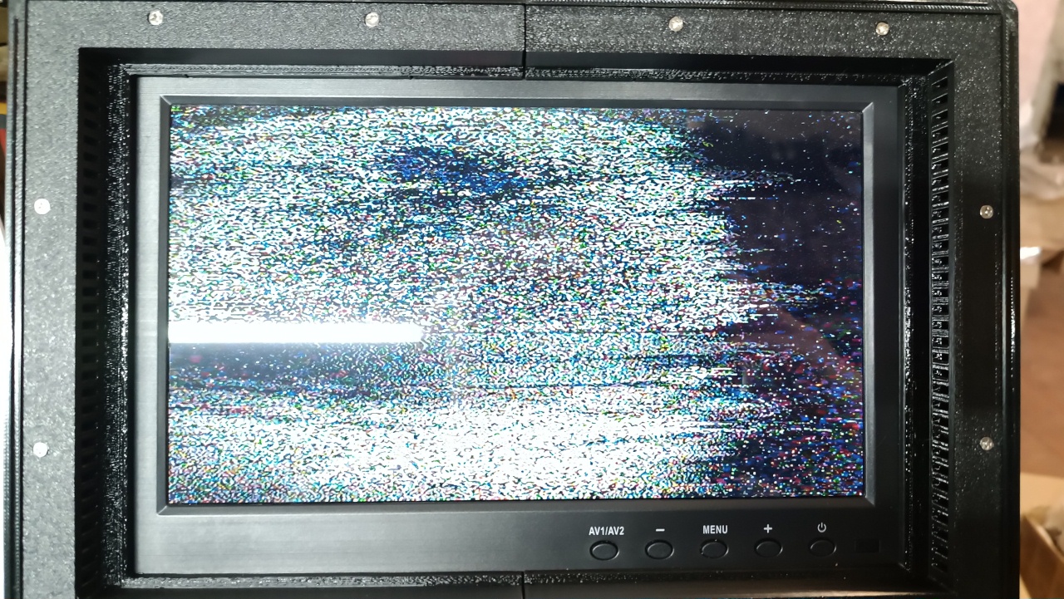
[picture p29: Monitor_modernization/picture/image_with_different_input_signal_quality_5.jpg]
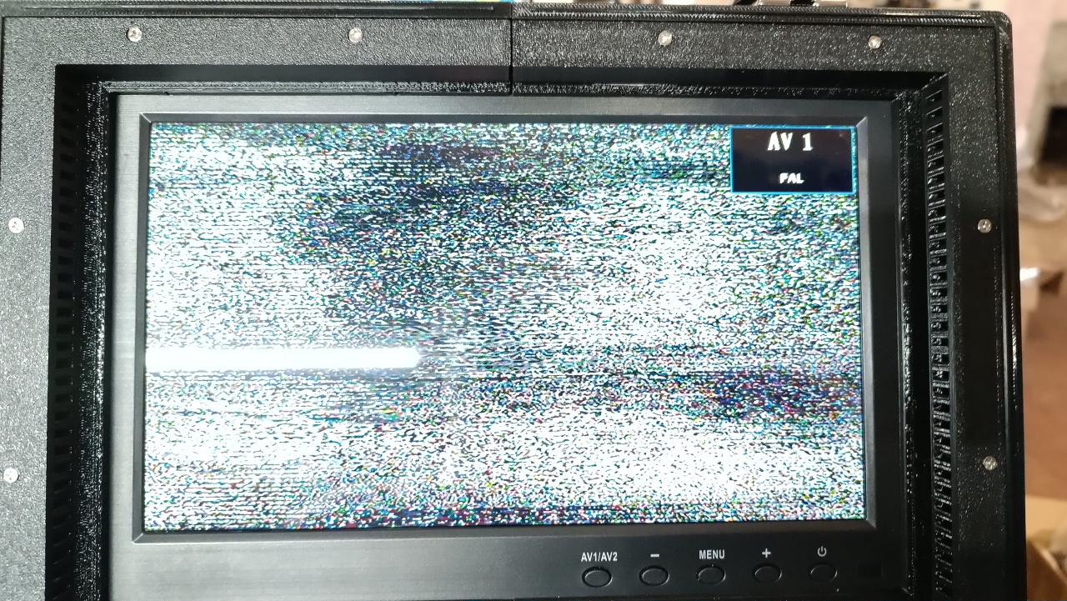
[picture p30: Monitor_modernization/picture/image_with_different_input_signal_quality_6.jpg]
 

หากสัญญาณส่วนใหญ่ประกอบไปด้วย static noise ("snow") monitor ก็อาจจะยังคงเปลี่ยนเข้าสู่โหมด "blue screen" ได้ ในกรณีนี้ คุณสามารถเชื่อมต่อแว่น goggles เข้ากับ station control unit ผ่าน connector XS4, XS5 หรือ XS6 แม้ว่าโอกาสในการสกัดสัญญาณที่เป็นประโยชน์ออกมาจากสัญญาณรบกวนที่ต่อเนื่องนั้นจะเป็นไปได้ยากก็ตาม

การปรากฏข้อความ "AV 1 PAL" ขึ้นอย่างต่อเนื่องบนพื้นหลังที่มี noise รุนแรง ถือเป็นสัญญาณบ่งชี้ว่าระบบกำลังทำงานอยู่ที่ขีดจำกัดสูงสุด นี่คือสัญญาณเตือนผู้ปฏิบัติงาน (operator): ระบบการรักษาเสถียรภาพสัญญาณซิงโครไนซ์ของ AT7456E chip ยังคงพยายามประคองอยู่ แต่ในเวลาใดก็ตาม monitor อาจตัดเข้าสู่โหมด "blue screen" เนื่องจากฝั่ง input ของชิปได้รับ noise เข้ามามากเกินไป

ทันทีที่มีสัญญาณที่เป็นประโยชน์เพียงเล็กน้อยที่สามารถระบุได้ปรากฏขึ้นในกระแสสัญญาณรบกวน ชิป AT7456E จะทำการฟื้นฟูการซิงโครไนซ์ในทันที และภาพบน monitor จะกลับมาปรากฏขึ้นอีกครั้ง

## Monitor Modernization - Practical Implementation

การปรับปรุงใช้งานจริงประกอบด้วยการประกอบวงจรดังต่อไปนี้:

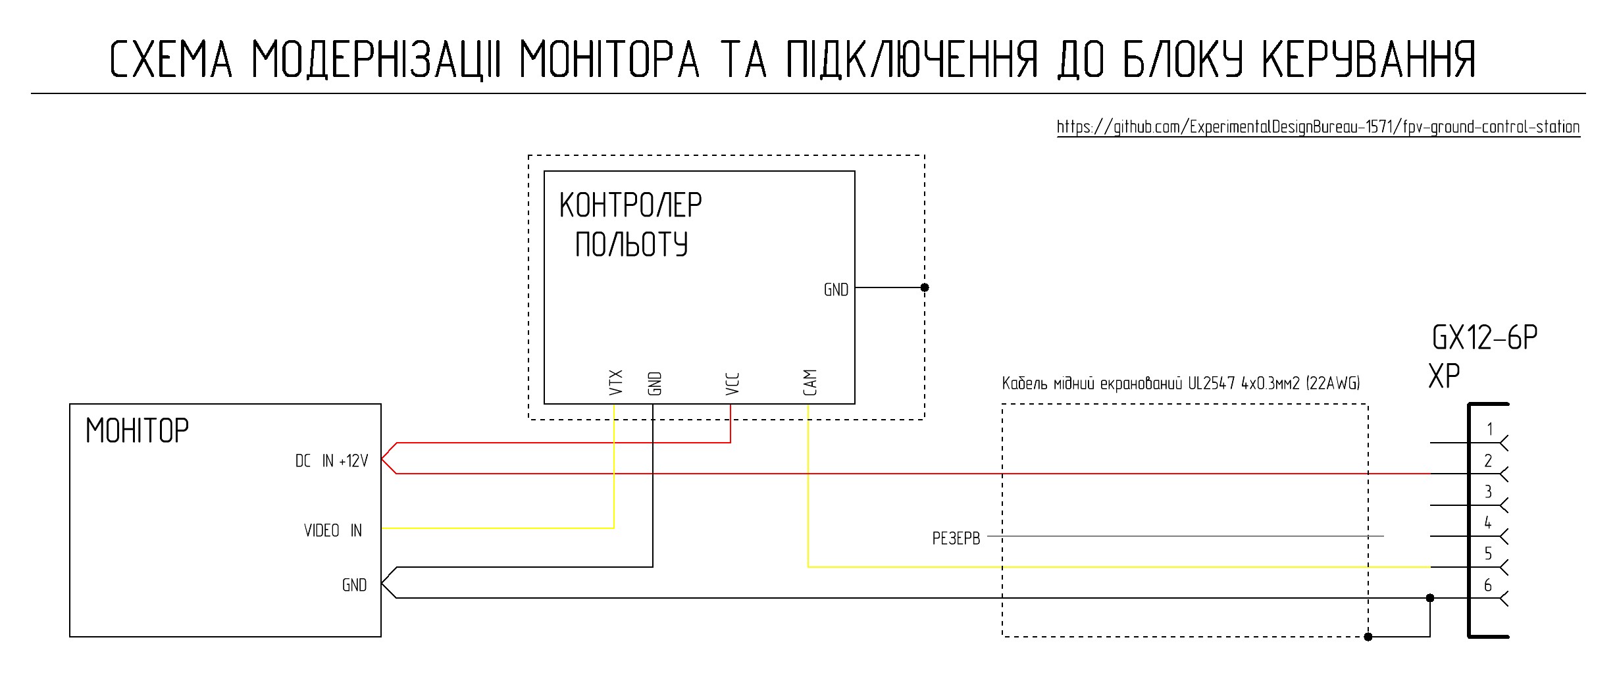
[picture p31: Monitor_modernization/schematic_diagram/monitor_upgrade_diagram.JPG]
Monitor modernization diagram


ในด้านโครงสร้าง flight controller จะถูกบรรจุอยู่ภายใน monitor housing และยึดให้แน่นหนาโดยใช้สกรูและน็อต M3

เนื่องจากการทำงานในพื้นที่ปิด จึงแนะนำให้ติดตั้ง copper heatsink เพื่อรักษาระดับอุณหภูมิ (temperature modes) ของชิป AT7456E และ microcontroller ของ flight controller โดยการถ่ายเทความร้อนไปยัง heatsink จะทำผ่าน silicone thermal interface ภาพเขียนแบบของ copper heatsink แสดงอยู่ด้านล่างนี้

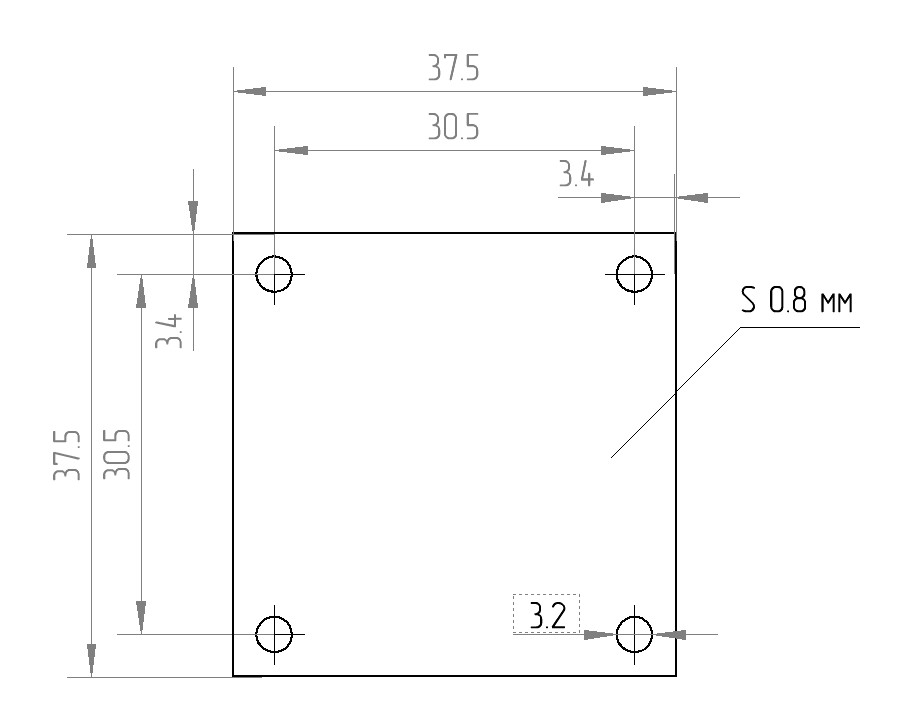
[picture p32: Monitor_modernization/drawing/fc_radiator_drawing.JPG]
Flight controller heatsink drawing


copper heatsink จะถูกเชื่อมต่อเข้ากับ common ground wire และทำหน้าที่เป็นแผงป้องกันเพิ่มเติม (additional shielding) สำหรับ AT7456E chip ส่วนชีลด์ (shield connection) ของสายเคเบิล UL2547 4x0.3mm2 (22AWG) จะเชื่อมต่อเข้ากับ common ground เฉพาะทางฝั่ง connector เท่านั้น เพื่อป้องกันไม่ให้เกิด ground loop

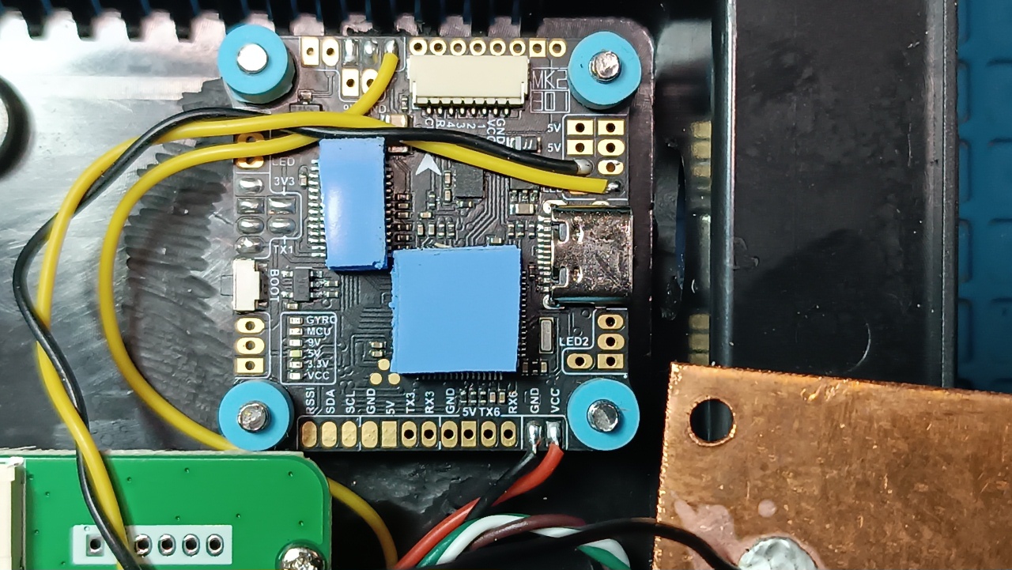
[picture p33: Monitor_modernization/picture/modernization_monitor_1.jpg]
Monitor modernization process
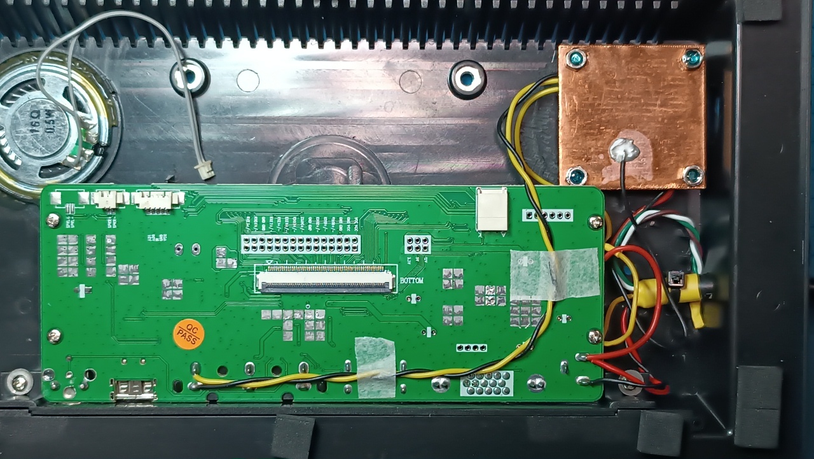
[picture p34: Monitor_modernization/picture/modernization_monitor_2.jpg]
Monitor modernization process
 

**ข้อมูลสำคัญเพิ่มเติม:** โปรดมั่นใจว่าได้ตั้งค่ามาตรฐาน PAL ในการตั้งค่าของ monitor, OSD menu ของ flight controller และการตั้งค่าสัญญาณ output ของกล้อง สำหรับการตรวจติดตามแรงดันไฟฟ้าของบัส +12V ที่จ่ายพลังงานให้กับ monitor คุณสามารถตั้งค่าการแสดงแรงดันนี้ในส่วนการตั้งค่า OSD menu ของ flight controller ได้ และด้วยเงื่อนไขสภาพการใช้งาน ขอแนะนำให้ป้องกันหน้าจอ LCD ด้วย hydrogel film ซึ่งสามารถติดได้โดยง่ายในขั้นตอนแยกชิ้นส่วนเพื่อประกอบตัว monitor

## List of Necessary Components for the Modernization of One Monitor

| Name | Quantity | Note |
|:---: | :---: | :---: |
| Flight controller with AT7456E | 1 pc | | 
| Damping standoff for flight controller M3*8 mm | 4 pcs |  | 
| Damping standoff for flight controller M3*4 mm | 4 pcs |  | 
| Screw M3x18 DIN 7985 A2 | 4 pcs | ยึด flight controller และ cooling heatsink เข้ากับ monitor housing | 
| Nut M3 DIN 934 | 4 pcs | ยึด flight controller และ cooling heatsink เข้ากับ monitor housing | 
| Silicone thermal pad 4 mm 3.5W\m.k | 25 mm x 20 mm | การถ่ายเทความร้อนจากชิป AT7456E และ STM32 ไปยัง copper heatsink | 
| Sheet copper 0.8 mm thick | 37.5 mm x 37.5 mm | Cooling heatsink | 
| Copper wire 26 AWG with silicone insulation, black | 310 mm | สายเคเบิล UL2547 -> FC = 120 mm; FC -> monitor = 210 mm | 
| Copper wire 26 AWG with silicone insulation, yellow | 330 mm | FC -> monitor = 210 mm; FC -> copper heatsink = 100 mm |
| Copper wire 26 AWG with silicone insulation, red | 100 mm | monitor -> FC |
| Copper shielded cable UL2547 4x0.3mm2 (22AWG) | 365 mm | การแบ่งความยาว: 85 mm ภายใน monitor และ 280 mm ภายนอก monitor |
| GX12-6 pin cable socket (female) | 1 pc |  |
| Hydrogel film for monitor protection | 225 mm x 128 mm |  |

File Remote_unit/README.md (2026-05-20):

# Remote unit

Remote unit คือ functional component ของ ground control station ที่ออกแบบมาเพื่อผสานรวม video reception systems, control signal transmission และ antenna-feeder equipment เข้าด้วยกัน Remote unit เป็น modular platform ที่ช่วยให้สามารถปรับเปลี่ยน configuration ได้ตามภารกิจ, ประเภทของ video system หรือสภาพการใช้งาน

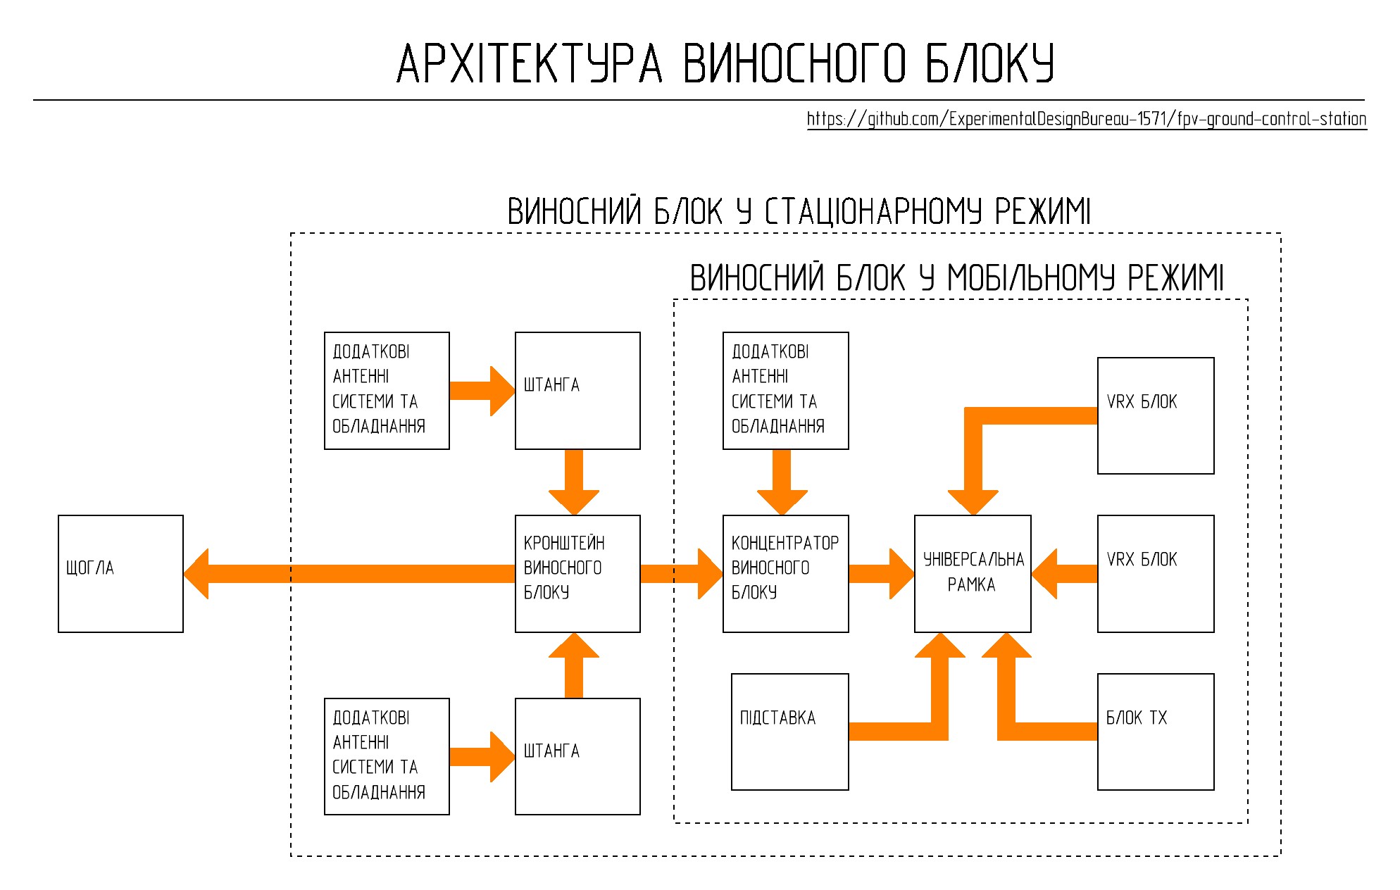
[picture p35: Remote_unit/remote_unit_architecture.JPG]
Remote unit architecture


การออกแบบของ Remote unit ช่วยรองรับ:
- mechanical and electrical integration ของ remote unit peripherals
- การใช้ TX และ VRX units ที่สามารถสับเปลี่ยนกันได้
- การปรับเปลี่ยน configuration ของ peripheral devices โดยไม่ต้องเปลี่ยนโครงสร้างของ station subsystems อื่นๆ
- การติดตั้ง high-frequency modules ไว้ภายนอก station control unit
- การผสานรวม antenna systems เพิ่มเติม
- การทำงานใน mobile และ stationary modes
- การติดตั้งบน mast หรือ supporting structures อื่นๆ
- การปรับเปลี่ยนสถานะของสถานีอย่างรวดเร็วระหว่างตำแหน่ง transport และ operational

## Operating Modes

### Mobile Mode

Remote unit สามารถใช้งานได้โดยไม่ต้องติดตั้งบน mast เมื่อใช้งานในสภาวะที่มีความคล่องตัวสูง (high-mobility) หรือเมื่ออยู่ในระยะสายตาโดยตรง (direct line of sight)

### Stationary Mode

เพื่อปรับปรุงสภาวะการรับและส่งสัญญาณ Remote unit สามารถติดตั้งบน mast ได้โดยใช้ bracket ร่วมกับ antenna systems เพิ่มเติม

### Note

แนะนำให้ผลิต Remote unit ตามลำดับขั้นตอนดังต่อไปนี้:

1.	**[Remote unit hub](Remote_unit_hub/)**
2.	**[Universal frame](Universal_frame/)**
3.	**[Remote unit bracket](Remote_unit_bracket/)**

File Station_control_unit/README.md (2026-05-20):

# Station control unit

Station control unit ใช้สำหรับ power distribution and switching, signal concentration, และ signal switching ระหว่าง remote unit และ peripheral devices

General view of the control unit

## Quick technical specifications of the station control unit

| Parameter | Value | Note |
|---|---|---|
| Input voltage | แบตเตอรี่ 6S Li-ion/LiPo (Min 22.2V Max 25.2V) | ผ่าน XT60 |
| Power protection | Fuse 5A | FU1 |
| Power switching | Toggle switches | SA1 (station main power), SA2 (remote unit power) |
| Power bus | +BAT | ตรงจากแบตเตอรี่ |
| Auxiliary buses | +12V, +5V | สร้างโดย DC-DC converters |
| Max current on the +12V bus | สูงสุด 3 A | โหลดทั้งหมด (Total load) |
| Number of video inputs | 1 (พร้อมตัวเลือกในการเลือก active video input บน remote unit) | Toggle switch SA3 |
| Input video signal type | Analog differential | |
| Number of video outputs | 4 | XS4–XS7 |
| Output video signal type | Analog composite (CVBS) | |
| Video processing | Amplification / conversion / splitting / filtering | VA-Di-2/4 module |
| Video level adjustment | มี | R1 potentiometer |
| Video noise filtering | มี | Toggle switch SA4 |
| BYPASS mode | มี | Connectors XS8–XS9 |
| TX interface | มี | ผ่าน XS2 |
| VRX control | รองรับ | ผ่าน XS3 |
| Cooling | Passive | Copper heatsinks + ช่องระบายอากาศ |
| Shielding | Partial | Shielding ของ voltage converters ด้วย copper heatsinks |

### Interfaces

| Connector | Purpose | Main signals | Note |
|---|---|---|---|
| XS1 (GX20-8) | การเชื่อมต่อกับ Remote unit | +BAT, GND, differential lines | ช่องทางการสื่อสารหลัก (Main communication channel) |
| XS2 (GX12-6) | Remote control (TX) | +BAT, GND, differential line | |
| XS3 (GX12-6) | VRX1 / remote unit peripheral control | +BAT, GND, differential line | ตัวเลือกเพิ่มเติม (Optional) |
| XS4 (GX12-6) | Video output 1 | +BAT, +12V, GND, CVBS | Monitor, goggles, DVR video recorder, video capture card สำหรับ streaming, ฯลฯ |
| XS5 (GX12-6) | Video output 2 | +BAT, +12V, GND, CVBS | Monitor, goggles, DVR video recorder, video capture card สำหรับ streaming, ฯลฯ |
| XS6 (GX12-6) | Video output 3 | +BAT, +12V, GND, CVBS | Monitor, goggles, DVR video recorder, video capture card สำหรับ streaming, ฯลฯ |
| XS7 (GX12-6) | Video output 4 (monitor) | +BAT, +12V, GND, CVBS | การเชื่อมต่อ Monitor |
| XS8 (GX12-6) | BYPASS (output) | +BAT, +12V, GND, CVBS | การเชื่อมต่อตรง (Direct connection) |
| XS9 (GX12-6) | BYPASS (input) | +BAT, +12V, GND, CVBS | แหล่งสัญญาณ (Signal source) |
| XT60 | Power input | +BAT, GND | ผ่าน Fuse |

## Schematic design and functionality of the station control unit

Schematic diagram of the control unit

แหล่งจ่ายไฟถูกส่งไปยัง control unit จากแบตเตอรี่ 6S3P Li-ion/LiPo ผ่าน fuse FU1 ขนาด 5A และจ่ายไปที่ toggle switch SA1 การเปิด toggle switch SA1 จะเป็นการจ่ายไฟไปยังบัส +BAT ซึ่งจ่ายพลังงานทั่วไปให้กับ ground control station

remote unit เชื่อมต่อกับ control unit ผ่านสาย cables ทาง connector XS1 ตัว remote control เชื่อมต่อผ่าน JR module ด้วยตัวแปลง CRSF -> RS-485 ไปยัง connector XS2 ส่วน connector XS3 จะใช้เมื่อต้องการ remote control ของ video receiver ผ่านสาย twisted pair (โปรดทราบว่าฟังก์ชันนี้ใช้ได้เฉพาะกับ video input ช่องที่ 1 ของ remote unit เท่านั้น) หากจำเป็น สามารถใช้สาย twisted pair จาก connector XS3 เพื่อส่งสัญญาณควบคุมไปยัง peripheral devices อื่นๆ ของ remote unit ได้ พลังงานจะถูกจ่ายไปยัง connectors XS1, XS2, และ XS3 จากบัส +BAT ผ่าน toggle switch SA2

การเชื่อมต่อของอุปกรณ์ peripheral video (เช่น monitor, goggles, DVR video recorder, video capture card สำหรับ streaming ฯลฯ) จะทำผ่าน connectors XS4, XS5, XS6, และ XS7 โดย connector XS7 จะถูกจองไว้สำหรับ monitor ที่ติดตั้งภายในตัวสถานี connectors XS4, XS5, XS6, และ XS7 จะรับพลังงานจากบัส +BAT และ +12V สัญญาณ video ไปยัง connectors XS4, XS5, XS6, และ XS7 มาจาก active video amplifier-splitter ซึ่งใช้ไฟเลี้ยงจากบัส +5V โดยมีตัวเลือกในการเลือก active video input บน remote unit (toggle switch SA3), ฟังก์ชันลดสัญญาณรบกวน (noise reduction) เมื่อมีสัญญาณรบกวนรุนแรง (toggle switch SA4), และการปรับระดับ video (video level adjustment) ผ่านตัวต้านทานปรับค่าได้ R1 (video level)

หากจำเป็นต้องส่งสัญญาณ video ไปยัง monitor โดยตรง สามารถใช้ตัวเลือก "BYPASS" ได้ (connectors XS8 และ XS9) โดยการเชื่อมต่อ monitor เข้ากับ connector XS8 และเชื่อมต่อแหล่งสัญญาณ video เข้ากับ connector XS9 ส่วนพลังงานจะถูกจ่ายไปยัง connectors XS8 และ XS9 จากบัส +BAT และ +12V

พลังงานของบัส +12V และ +5V ได้มาจาก voltage converters การระบายความร้อนจาก converters จะใช้ copper heatsinks จำนวนสองตัวผ่าน silicone thermal interface ตัว copper heatsinks จะเชื่อมต่อเข้ากับสายกราวด์ร่วม (GND) และเมื่อทำงานร่วมกับตัวเก็บประจุแบบเซรามิก (ceramic capacitors) ที่เอาต์พุตของ voltage converters จะช่วยลดสัญญาณรบกวน (parasitic noise) จากการทำงานของ converters ให้เหลือน้อยที่สุด โหลดต่อเนื่องทั้งหมดบนบัส +12V ผ่าน connectors XS4, XS5, XS6, XS7, XS8, และ XS9 จะต้องไม่เกิน 3A

station control unit มีความหนาแน่นของอุปกรณ์ (component density) สูง และต้องทำงานกับระดับแรงดันไฟฟ้าที่หลากหลาย ความสำเร็จในการประกอบอุปกรณ์นี้ต้องอาศัยทักษะการอ่าน schematic และประสบการณ์ในการประกอบงานที่มีความซับซ้อนระดับปานกลาง

Assembly process of the control unit

## List of necessary components for manufacturing one control unit

| Component Name | Quantity | Note |
| :--- | :--- | :---: |
| 100DP1T1B1M1QEH toggle switch หรือ MTS-202 6-pin ON-ON ที่หาได้ทั่วไป | 4 ชิ้น | SA1-SA4 (หมายเหตุ: toggle switches ที่หาได้ทั่วไปต้องได้รับการปรับแต่งเพื่อความน่าเชื่อถือในการสลับสัญญาณ!) |
| WH148 1 kOhm potentiometer | 1 ชิ้น | ตัวปรับระดับ video (Video level regulator) |
| WH148 potentiometer knob | 1 ชิ้น | |
| VideoLink VA-Di-2/4 video amplifier-splitter | 1 ชิ้น | โมดูลที่ผลิตในยูเครน [สั่งซื้อ VideoLink VA-Di-2/4 จากผู้ผลิต](https://sezam.video/shop/videopidsilyuvach-videolink-va-di-24/) |
| GUTI ELECTRONICS BEC12S-PRO voltage converter | 1 ชิ้น | อุปกรณ์สัญชาติยูเครนที่เทียบเท่า Matek BEC 12S PRO [สั่งซื้อ GUTI ELECTRONICS BEC12S-PRO จากผู้ผลิต](https://prom.ua/ua/p2814749849-otechestvennyj-analog-matek.html) |
| GUTI ELECTRONICS mBEC12S voltage converter | 1 ชิ้น | อุปกรณ์สัญชาติยูเครนที่เทียบเท่า Matek BEC 12S [สั่งซื้อ GUTI ELECTRONICS mBEC12S จากผู้ผลิต](https://prom.ua/ua/p2814749850-otechestvennyj-analog-matek.html) |
| DSN-DVM-368 0-30V voltmeter | 1 ชิ้น | |
| GX20-8 pin panel mount plug (male) | 1 ชิ้น | XS1 |
| GX12-6 pin panel mount plug (male) | 8 ชิ้น | XS2-XS9 |
| XT60E-M connector | 1 ชิ้น | |
| FH-501 (KLS5-701) fuse holder | 1 ชิ้น | |
| FT Standard 5A fuse | 1 ชิ้น | |
| แผ่นทองแดงหนา 0.8 mm | 134 mm x 40 mm | Cooling heatsinks สำหรับ power distribution module |
| Silicone thermal pad 1.5 mm 6W/m.k | 84 mm x 24 mm | การระบายความร้อนจาก voltage converters ไปยัง cooling heatsinks |
| Silicone thermal pad 1 mm 6W/m.k | 18 mm x 16 mm | การระบายความร้อนจาก voltage converters ไปยัง cooling heatsinks |
| แผ่นไฟเบอร์กลาสเคลือบทองแดงหน้าเดียว (FR4) 1.5 mm | 35 mm x 17 mm | บอร์ด power bus ใน power distribution module |
| สายไฟทองแดง 26 AWG หุ้มฉนวนซิลิโคน, สีดำ | 760 mm | |
| สายไฟทองแดง 26 AWG หุ้มฉนวนซิลิโคน, สีแดง | 250 mm | |
| สายไฟทองแดง 26 AWG หุ้มฉนวนซิลิโคน, สีเหลือง | 490 mm | |
| สายไฟทองแดง 26 AWG หุ้มฉนวนซิลิโคน, สีน้ำเงิน | 410 mm | |
| สายไฟทองแดง 26 AWG หุ้มฉนวนซิลิโคน, สีเขียว | 660 mm | |
| สายไฟทองแดง 20 AWG หุ้มฉนวนซิลิโคน, สีดำ | 1540 mm | |
| สายไฟทองแดง 20 AWG หุ้มฉนวนซิลิโคน, สีแดง | 2140 mm | |
| สายไฟทองแดง 20 AWG หุ้มฉนวนซิลิโคน, สีเหลือง | 1060 mm | |
| สกรู M2x8 DIN 7985 | 14 ชิ้น | |
| สกรู M2.5x8 DIN 965 | 2 ชิ้น | |
| สกรู M2.5x12 DIN 7985 | 2 ชิ้น | |
| สกรู M3x8 DIN 7985 A2 | 2 ชิ้น | |
| สกรู M3x16 DIN 7985 A2 | 4 ชิ้น | |
| แหวนรอง M2 DIN 125 | 14 ชิ้น | |
| แหวนรอง M2.5 DIN 125 | 2 ชิ้น | |
| แหวนรอง M3 DIN 125 | 2 ชิ้น | |
| น็อตตัวเมีย M2 DIN 934 | 14 ชิ้น | |
| น็อตตัวเมีย M2.5 DIN 934 | 2 ชิ้น | |
| น็อตตัวเมีย M3 DIN 934 | 6 ชิ้น | |
| สกรูเกลียวปล่อย 2x8 DIN 7982 | 8 ชิ้น | |
| Part 1 - 3D print | 1 ชิ้น | |
| Part 2 - 3D print | 1 ชิ้น | |
| Part 3 - 3D print | 1 ชิ้น | |
| Part 4 - 3D print | 1 ชิ้น | |

## 3D printing settings and material used

| Parameter | Value |
| :---: | :---: |
| Wall line count (perimeters) | 4 |
| Top and bottom solid layers | 5 |
| Infill density | 40% |
| Infill pattern | Gyroid |
| Supports | Tree-like |

Material: coPET black MonoFilament

## Modernization of MTS-202 toggle switches (6-pin, ON-ON)

การหาซื้อ toggle switches คุณภาพสูงอาจเป็นเรื่องยาก แต่รุ่นที่หาได้ทั่วไปสามารถนำมาดัดแปลงให้ทำงานได้อย่างน่าเชื่อถือได้อย่างง่ายดาย การทำ modernization นี้ช่วยปรับปรุงความน่าเชื่อถือในการสลับสัญญาณ

### Steps for performing the work:

1. **Disassembly:** ถอดประกอบ toggle switch อย่างระมัดระวังโดยการดัดแท็บโลหะของตัว housing กลับขึ้นมา

Disassembled MTS-202 toggle switch

2. **Contact preparation:** ถอด rocker arms (moving contacts) ออกมาแล้วดัดให้โค้งงอเล็กน้อยเพื่อให้สัมผัสกันได้อย่างมั่นคง

Rocker arm (moving contact) of the MTS-202 toggle switch Modernized rocker arm (moving contact) of the MTS-202 toggle switch

3. **Lubrication:** เพื่อลดการสึกหรอและปรับปรุงความลื่นไหลในการเลื่อน ให้ทาจาระบีซิลิโคนหนา (thick silicone grease) ปริมาณเล็กน้อยลงบนตัวผลักพลาสติก (plastic pusher) ของ toggle switch
4. **Assembly:** ประกอบ toggle switch กลับคืนในลำดับย้อนกลับ แล้วยึดฝาครอบโลหะให้แน่นด้วยแท็บโลหะ
5. **Testing:** ตรวจสอบการทำงานของ toggle switch โดยใช้ multimeter

## Detailed list of hardware usage

| Component Name | Type/Size | Quantity | Note |
| :--- | :--- | :---: | :---: |
| Screw | M2x8 DIN 7985 | 4 ชิ้น | การยึด power bus PCB เข้ากับ Part 4 |
| Screw | M2x8 DIN 7985 | 10 ชิ้น | การยึด heatsinks เข้ากับ Part 4 |
| Screw | M2.5x8 DIN 965 | 2 ชิ้น | การยึด XT60 power connector เข้ากับ Part 1 |
| Screw | M2.5x12 DIN 7985 | 2 ชิ้น | การยึด voltmeter เข้ากับ Part 2 |
| Screw | M3x8 DIN 7985 A2 | 2 ชิ้น | การยึด fuse holder เข้ากับ Part 1 |
| Screw | M3x16 DIN 7985 A2 | 4 ชิ้น | การยึด power distribution module เข้ากับ Part 3 |
| Washer | M2 DIN 125 | 4 ชิ้น | การยึด power bus PCB เข้ากับ Part 4 |
| Washer | M2 DIN 125 | 10 ชิ้น | การยึด heatsinks เข้ากับ Part 4 |
| Washer | M2.5 DIN 125 | 2 ชิ้น | การยึด voltmeter เข้ากับ Part 2 |
| Washer | M3 DIN 125 | 2 ชิ้น | การยึด power distribution module เข้ากับ Part 3 |
| Nut | M2 DIN 934 | 4 ชิ้น | การยึด power bus PCB เข้ากับ Part 4 |
| Nut | M2 DIN 934 | 10 ชิ้น | การยึด heatsinks เข้ากับ Part 4 |
| Nut | M2.5 DIN 934 | 2 ชิ้น | การยึด voltmeter เข้ากับ Part 2 |
| Nut | M3 DIN 934 | 2 ชิ้น | การยึด fuse holder เข้ากับ Part 1 |
| Nut | M3 DIN 934 | 4 ชิ้น | การยึด power distribution module เข้ากับ Part 3 |
| Screw | 2x8 DIN 7982 | 4 ชิ้น | การยึด Part 2 เข้ากับ Part 1 |
| Screw | 2x8 DIN 7982 | 4 ชิ้น | การยึด Part 3 เข้ากับ Part 1 |

## Detailed list of wire usage

### XS1
| Type | Length | Note |
| :--- | :--- | :---: |
| 20 AWG black | 100 mm | XS1 - บัส GND ของ power distribution module |
| 20 AWG red | 160 mm | XS1 - SA2 |
| 26 AWG green | 110 mm | XS1 - VA-Di-2/4 |
| 26 AWG blue | 110 mm | XS1 - VA-Di-2/4 |

### XS2
| Type | Length | Note |
| :--- | :--- | :---: |
| 20 AWG black | 140 mm | XS2 - บัส GND ของ power distribution module |
| 20 AWG red | 110 mm | XS2 - SA2 |
| 26 AWG green | 100 mm | XS2 - XS1 |
| 26 AWG blue | 100 mm | XS2 - XS1 |

### XS3
| Type | Length | Note |
| :--- | :--- | :---: |
| 20 AWG black | 140 mm | XS3 - บัส GND ของ power distribution module |
| 20 AWG red | 110 mm | XS3 - SA2 |
| 26 AWG green | 100 mm | XS3 - XS1 |
| 26 AWG blue | 100 mm | XS3 - XS1 |

### XS4
| Type | Length | Note |
| :--- | :--- | :---: |
| 20 AWG black | 150 mm | XS4 - บัส GND ของ power distribution module |
| 20 AWG red | 150 mm | XS4 - บัส +BAT ของ power distribution module |
| 20 AWG yellow | 150 mm | XS4 - บัส +12V ของ power distribution module |
| 26 AWG yellow | 110 mm | XS4 - VA-Di-2/4 |

### XS5
| Type | Length | Note |
| :--- | :--- | :---: |
| 20 AWG black | 150 mm | XS5 - บัส GND ของ power distribution module |
| 20 AWG red | 150 mm | XS5 - บัส +BAT ของ power distribution module |
| 20 AWG yellow | 150 mm | XS5 - บัส +12V ของ power distribution module |
| 26 AWG yellow | 100 mm | XS5 - VA-Di-2/4 |

### XS6
| Type | Length | Note |
| :--- | :--- | :---: |
| 20 AWG black | 160 mm | XS6 - บัส GND ของ power distribution module |
| 20 AWG red | 160 mm | XS6 - บัส +BAT ของ power distribution module |
| 20 AWG yellow | 160 mm | XS6 - บัส +12V ของ power distribution module |
| 26 AWG yellow | 100 mm | XS6 - VA-Di-2/4 |

### XS7
| Type | Length | Note |
| :--- | :--- | :---: |
| 20 AWG black | 170 mm | XS7 - บัส GND ของ power distribution module |
| 20 AWG red | 170 mm | XS7 - บัส +BAT ของ power distribution module |
| 20 AWG yellow | 170 mm | XS7 - บัส +12V ของ power distribution module |
| 26 AWG yellow | 110 mm | XS7 - VA-Di-2/4 |

### XS8
| Type | Length | Note |
| :--- | :--- | :---: |
| 20 AWG black | 170 mm | XS8 - บัส GND ของ power distribution module |
| 20 AWG red | 170 mm | XS8 - บัส +BAT ของ power distribution module |
| 20 AWG yellow | 170 mm | XS8 - บัส +12V ของ power distribution module |
| 26 AWG yellow | 70 mm | XS8 - XS9 |

### XS9
| Type | Length | Note |
| :--- | :--- | :---: |
| 20 AWG black | 160 mm | XS9 - บัส GND ของ power distribution module |
| 20 AWG red | 160 mm | XS9 - บัส +BAT ของ power distribution module |
| 20 AWG yellow | 160 mm | XS9 - บัส +12V ของ power distribution module |

### XT60
| Type | Length | Note |
| :--- | :--- | :---: |
| 20 AWG black | 100 mm | XT60 - บัส GND ของ power distribution module |
| 20 AWG red | 50 mm | XT60 - Fuse holder |

### Fuse holder
| Type | Length | Note |
| :--- | :--- | :---: |
| 20 AWG red | 120 mm | Fuse holder - SA1 |

### Voltmeter
| Type | Length | Note |
| :--- | :--- | :---: |
| 26 AWG black | 170 mm | Voltmeter - บัส GND ของ power distribution module |
| 26 AWG red | 170 mm | Voltmeter - บัส +BAT ของ power distribution module |

### SA1
| Type | Length | Note |
| :--- | :--- | :---: |
| 20 AWG red | 170 mm | SA1 - บัส +BAT ของ power distribution module |
| 20 AWG red | 100 mm | SA1 - SA1 jumpers |

### SA2
| Type | Length | Note |
| :--- | :--- | :---: |
| 20 AWG red | 170 mm | SA2 - บัส +BAT ของ power distribution module |
| 20 AWG red | 100 mm | SA2 - SA2 jumpers |

### SA3
| Type | Length | Note |
| :--- | :--- | :---: |
| 26 AWG black | 100 mm | SA3 - VA-Di-2/4 |
| 26 AWG black | 30 mm | SA3 - SA4 |
| 26 AWG blue | 100 mm | SA3 - VA-Di-2/4 |

### SA4
| Type | Length | Note |
| :--- | :--- | :---: |
| 26 AWG green | 100 mm | SA4 - VA-Di-2/4 |

### R1
| Type | Length | Note |
| :--- | :--- | :---: |
| 26 AWG black | 30 mm | R1 - VA-Di-2/4 |

### VA-Di-2/4
| Type | Length | Note |
| :--- | :--- | :---: |
| 26 AWG black | 170 mm | VA-Di-2/4 - บัส GND ของ power distribution module |
| 26 AWG green | 170 mm | VA-Di-2/4 - บัส +5V ของ power distribution module |

### Power distribution module
| Type | Length | Note |
| :--- | :--- | :---: |
| 26 AWG black | 80 mm | Large heatsink - บัส GND ของ power distribution module |
| 26 AWG black | 80 mm | Small heatsink - บัส GND ของ power distribution module |
| 26 AWG black | 80 mm | 12S voltage converter - บัส GND ของ power distribution module |
| 26 AWG red | 80 mm | 12S voltage converter - บัส +BAT ของ power distribution module |
| 26 AWG green | 80 mm | 12S voltage converter - บัส +5V ของ power distribution module |
| 20 AWG black | 100 mm | 12S PRO voltage converter - บัส GND ของ power distribution module |
| 20 AWG red | 100 mm | 12S PRO voltage converter - บัส +BAT ของ power distribution module |
| 20 AWG yellow | 100 mm | 12S PRO voltage converter - บัส +12V ของ power distribution module |

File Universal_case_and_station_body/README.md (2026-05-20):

# Universal case and station body

การออกแบบ universal case ได้รับการพัฒนาให้เป็นโซลูชันที่สมดุลสำหรับการขนส่งและการใช้งาน FPV drone ground control station ในภาคสนาม โดยจุดมุ่งหมายหลักในการออกแบบคือการผสมผสานระหว่างความน่าเชื่อถือ (reliability), ความคล่องตัว (mobility), และความสามารถในการผลิตได้ง่าย (manufacturing accessibility)

General view of finished cases

## Key design features:
<ul>
<li><b>Compactness and mobility:</b> ขนาดของตัว body ได้รับการปรับปรุงให้เหมาะสมเพื่อความคล่องตัวสูงสุดของผู้ใช้งาน รูปทรงที่กะทัดรัด (compact form factor) ของ case ช่วยให้ขนส่งสถานีในกระเป๋าเป้หรือเป็นอุปกรณ์ชิ้นเล็กๆ แยกต่างหากได้อย่างสะดวกสบาย</li>

<li><b>Optimization for additive manufacturing:</b> รูปทรงเรขาคณิตของชิ้นส่วนต่างๆ ได้รับการออกแบบสำหรับการพิมพ์ 3D printing บนเครื่องพิมพ์ FDM ทั่วไป ขนาดสูงสุดของชิ้นส่วนเดี่ยวแต่ละชิ้นไม่เกิน 250 × 250 × 250 mm ทำให้โครงการนี้สามารถทำได้จริงบนอุปกรณ์ราคาประหยัด</li>

<li><b>Cost effectiveness:</b> การออกแบบใช้หลักการลดต้นทุนการผลิตให้เหลือน้อยที่สุด การใช้วัสดุที่ราคาจับต้องได้ (พลาสติกประเภท PETG/ABS) และอุปกรณ์ hardware มาตรฐานช่วยลดต้นทุนของผลิตภัณฑ์สำเร็จรูปได้อย่างมากโดยไม่สูญเสียฟังก์ชันการทำงาน</li>

<li><b>Operational durability and repeatability:</b> การออกแบบมีเกณฑ์ความปลอดภัย (safety margin) ที่เพียงพอสำหรับการใช้งานหนัก โซลูชันทางเทคนิคช่วยให้ง่ายต่อการผลิตตัว body ซ้ำในโรงงานท้องถิ่นหรือโรงงานภาคสนาม</li>

<li><b>Modular architecture and maintainability:</b></li>
<ul>
<li>ตัว body ประกอบด้วยโมดูลแยกส่วนที่สามารถเปลี่ยนทดแทนกันได้</li>

<li>High maintainability: ในกรณีที่เกิดความเสียหายทางกลไก สามารถเปลี่ยนเฉพาะชิ้นส่วนที่เสียหายได้</li>

<li>Hardware unification: การเชื่อมต่อส่วนใหญ่ใช้ตัวยึดมาตรฐานเมตริก (สกรู M3 และน็อตตัวเมีย) ซึ่งช่วยลดความยุ่งยากในการประกอบและการจัดการชิ้นส่วน</li>
</ul>
</ul>

## Required quantity of components for manufacturing one universal case - station body

| Component Name | Type/Size | Quantity | Note |
| :---: | :---: | :---: | :---: |
| Self-tapping screw | 2x8 DIN 7982 | 12 ชิ้น | หากใช้ case เป็น station body |
| Screw | M3x14 DIN 7985 | 48 ชิ้น | |
| Screw | M3x20 DIN 7985 A2 | 10 ชิ้น | หากใช้ case เป็น station body |
| Screw | M3x25 DIN 912 | 7 ชิ้น | |
| Screw | M4x12 DIN 7985 | 4 ชิ้น | หากใช้ case เป็น station body |
| Nut | M3 DIN 934 | 65 ชิ้น | |
| Washer | M3 DIN 125 | 18 ชิ้น | |
| Lock with key | A-014/2 | 2 ชิ้น | [ซื้อ Lock with key A-014/2](https://prom.ua/ua/p2153719864-zamok-klyuchem-0142.html) |
| Hinges | B-114 | 2 ชิ้น | [ซื้อ Hinges B-114](https://prom.ua/ua/p779613844-petlya-114.html) |
| Part 1 |  | 1 ชิ้น | |
| Part 2 |  | 1 ชิ้น | |
| Part 3 |  | 1 ชิ้น | หากใช้ case เป็น station body |
| Part 4 |  | 1 ชิ้น | หากใช้ case เป็น station body |
| Part 5 |  | 1 ชิ้น | |
| Part 6 |  | 1 ชิ้น | |
| Part 7 |  | 2 ชิ้น | |
| Part 8 |  | 1 ชิ้น | |
| Part 9 |  | 1 ชิ้น | |

## 3D printing settings and material used

| Parameter | Value |
| :---: | :---: |
| Wall line count (perimeters) | 5 |
| Top and bottom solid layers | 5 |
| Infill density | 40% |
| Infill pattern | Gyroid |
| Supports | Tree-like |

Material: coPET black MonoFilament

## Detailed list of hardware usage

| Component Name | Type/Size | Quantity | Note |
| :---: | :---: | :---: | :---: |
| Screw | M3x14 DIN 7985 | 11 ชิ้น | การเชื่อมต่อระหว่าง Part 1 และ Part 2 |
| Nut | M3 DIN 934 | 11 ชิ้น | การเชื่อมต่อระหว่าง Part 1 และ Part 2 |

Part 1 and Part 2

| Component Name | Type/Size | Quantity | Note |
| :---: | :---: | :---: | :---: |
| Screw | M3x14 DIN 7985 | 17 ชิ้น | การเชื่อมต่อระหว่าง Part 5 และ Part 6 |
| Nut | M3 DIN 934 | 17 ชิ้น | การเชื่อมต่อระหว่าง Part 5 และ Part 6 |

Part 5 and Part 6

| Component Name | Type/Size | Quantity | Note |
| :---: | :---: | :---: | :---: |
| Screw | M3x14 DIN 7985 | 8 ชิ้น | การยึด locks เข้ากับ top cover และ base ของ universal case and station body |
| Nut | M3 DIN 934 | 8 ชิ้น | การยึด locks เข้ากับ top cover และ base ของ universal case and station body |

Mounting the locks to the top cover and the base of the universal case and station body

| Component Name | Type/Size | Quantity | Note |
| :---: | :---: | :---: | :---: |
| Screw | M3x14 DIN 7985 | 12 ชิ้น | การยึด hinges เข้ากับ top cover และ base ของ universal case and station body |
| Nut | M3 DIN 934 | 12 ชิ้น | การยึด hinges เข้ากับ top cover และ base ของ universal case and station body |
| Washer | M3 DIN 125 | 12 ชิ้น | การยึด hinges เข้ากับ top cover และ base ของ universal case and station body |

Mounting the hinges to the top cover and the base of the universal case and station body Mounting the hinges to the top cover and the base of the universal case and station body

| Component Name | Type/Size | Quantity | Note |
| :---: | :---: | :---: | :---: |
| Screw | M3x25 DIN 912 | 3 ชิ้น | การเชื่อมต่อระหว่าง Part 8 และ Part 9 |
| Nut | M3 DIN 934 | 3 ชิ้น | การเชื่อมต่อระหว่าง Part 8 และ Part 9 |
| Washer | M3 DIN 125 | 6 ชิ้น | การเชื่อมต่อระหว่าง Part 8 และ Part 9 |

Part 8 and Part 9

| Component Name | Type/Size | Quantity | Note |
| :---: | :---: | :---: | :---: |
| Screw | M3x25 DIN 912 | 4 ชิ้น | การเชื่อมต่อระหว่าง Part 7 และ base ของ universal case and station body |
| Nut | M3 DIN 934 | 4 ชิ้น | การเชื่อมต่อระหว่าง Part 7 และ base ของ universal case and station body |

Connection between Part 7 and the base of the universal case and station body

| Component Name | Type/Size | Quantity | Note |
| :---: | :---: | :---: | :---: |
| Screw | M3x20 DIN 7985 A2 | 10 ชิ้น | การยึด control unit เข้ากับ base ของ universal case and station body |
| Nut | M3 DIN 934 | 10 ชิ้น | การยึด control unit เข้ากับ base ของ universal case and station body |

Mounting the control unit to the base of the universal case and station body

| Component Name | Type/Size | Quantity | Note |
| :---: | :---: | :---: | :---: |
| Screw | M4x12 DIN 7985 | 4 ชิ้น | การยึด monitor เข้ากับ top cover ของ universal case and station body |

Mounting the monitor to the top cover of the universal case and station body

| Component Name | Type/Size | Quantity | Note |
| :---: | :---: | :---: | :---: |
| Self-tapping screw | 2x8 DIN 7982 | 6 ชิ้น | การยึด Part 3 เข้ากับ Part 1 |
| Self-tapping screw | 2x8 DIN 7982 | 6 ชิ้น | การยึด Part 4 เข้ากับ Part 2 |

Mounting Part 3 to Part 1 and Part 4 to Part 2

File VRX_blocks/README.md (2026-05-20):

# VRX Blocks

ส่วนนี้ประกอบด้วยเอกสารคู่มือ, 3D models, schematics และคำแนะนำสำหรับการผลิต interchangeable video receiver units (VRX blocks) ที่ใช้เป็นส่วนหนึ่งของ Ground Control Station โดยที่แต่ละ VRX block คือ module ที่ทำงานได้อย่างสมบูรณ์ในตัวเอง (functionally complete module) ซึ่งออกแบบมาให้ทำงานในย่านความถี่ (frequency band), มาตรฐานการส่งสัญญาณ (transmission standard) ที่เฉพาะเจาะจง หรือทำงานร่วมกับอุปกรณ์รับสัญญาณวิดีโอ (video receiver equipment) เฉพาะประเภท

## Purpose

VRX blocks ทำหน้าที่:
- video signal reception
- transmission of the output video signal ไปยัง switching lines ของ Ground Control Station
- mechanical integration ของ video receiver equipment เข้ากับ remote unit ของ station
- unified power and signal lines connection

## Architecture and Implementation Details

### The architecture supports the use of:
<ul>
<li>analog video receivers</li>
<li>digital video receiver systems ที่ประกอบร่วมกับ video signal converter</li>
<li>video receiver control ผ่านทาง Ground Control Station switching lines</li>
</ul>

VRX blocks architecture block diagram

### Implementation Details
<ul>
<li>VRX blocks ทั้งหมดมี unified connection เข้ากับ remote unit hub</li>
<li>VRX blocks ใหม่สามารถรวมเข้ากับ Ground Control Station ได้โดยไม่ต้องเปลี่ยนแปลงสถาปัตยกรรมของ subsystems อื่นๆ</li>
<li>แต่ละ VRX block ได้รับการออกแบบมาสำหรับอุปกรณ์รับสัญญาณวิดีโอ (video receiver equipment) หรือมาตรฐานการส่งสัญญาณ (transmission standard) เฉพาะประเภท</li>
<li>การออกแบบช่วยให้มั่นใจได้ว่า VRX blocks สามารถถอดเปลี่ยนได้โดยไม่ต้องแก้ไขส่วนประกอบอื่นๆ ของ station</li>
</ul>

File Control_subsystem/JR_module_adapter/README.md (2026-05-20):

# JR_module_adapter

JR_module_adapter ทำหน้าที่เชื่อมต่อ control panel ที่มี JR-compatible bay เข้ากับ station control unit เพื่อส่งผ่านและแลกเปลี่ยนข้อมูลแบบสองทิศทาง (two-way data exchange) กับ control transmitter ที่อยู่บน remote unit ของสถานี

General view of the JR module

## Brief Technical Parameters

| Parameter | Value | Note |
|---|---|---|
| Control protocol | CRSF | ผ่าน S.Port |
| Transmission interface | Differential signal ของมาตรฐาน RS-485 | |
| Operating mode | Two-way | Control + telemetry |
| JR module adapter power supply | 5–8.4 V | จาก control panel |
| Cooling | Passive | Heatsinks + ช่องระบายอากาศ |
| Shielding | Partial | |

### Interfaces

| Connector | Purpose | Main signals | Note |
|---|---|---|---|
| XS1 | การเชื่อมต่อกับ control panel | +BAT, GND, CRSF | Control panel ต้องมี JR-compatible bay |
| XS2 | การเชื่อมต่อกับ station control unit | Differential signal ของมาตรฐาน RS-485, GND | |

## Circuitry and Functionality of the JR Module Adapter

Adapter นี้ใช้พลังงานโดยตรงจาก control panel ผ่าน connector XS1 ในย่านแรงดัน 5V–8.4V

สัญญาณความเร็วสูง (high-speed signal) จาก control panel ผ่านขา S.Port pin (โปรโตคอล CRSF) ของ connector XS1 จะถูกส่งไปยัง interface converter (โมดูล BARVINOK-5 RS-485 nano V2.1) ซึ่งจะแปลงสัญญาณดังกล่าวเป็น differential signal ของมาตรฐาน RS-485 และส่งออกผ่าน connector XS2 ไปยัง switching lines ของ ground control station

การรักษาเสถียรภาพของอุณหภูมิของอุปกรณ์ (temperature modes) ใช้ระบบระบายความร้อนแบบ passive cooling ซึ่งประกอบด้วยช่องระบายอากาศใน housing, silicone thermal pad และ copper heatsink ตัว heatsink จะถูกเชื่อมต่อทางไฟฟ้ากับสายกราวด์ร่วม (GND) ทำให้สามารถทำหน้าที่เป็นแผงป้องกันเพิ่มเติม (additional shield) เพื่อป้องกันสัญญาณรบกวนทางแม่เหล็กไฟฟ้า (electromagnetic interference) ได้

Schematic diagram of the JR module

## List of Necessary Components for Manufacturing One JR Module Adapter

| Name | Quantity | Note |
| :--- | :--- | :---: |
| BARVINOK-5 RS-485 nano V2.1 interface converter module | 1 pc | โมดูลผลิตในยูเครน [ซื้อ BARVINOK-5 RS-485 nano V2.1 จากผู้ผลิต](https://prom.ua/ua/p2693881056-adapter-port-485.html) |
| PCE-C-05 connector | 1 pc | XS1 |
| GX12-6 pin panel mount plug (male) | 1 pc | XS2 |
| Double-sided prototyping board with 2.54 mm pitch | 30 mm x 70 mm |  |
| Sheet copper 0.8 mm thick | 25 mm x 28 mm |  |
| Silicone thermal pad 2 mm 6W/m.k | 25 mm x 28 mm |  |
| Copper wire 26 AWG with silicone insulation, black | 260 mm |  |
| Copper wire 26 AWG with silicone insulation, green | 170 mm |  |
| Copper wire 26 AWG with silicone insulation, blue | 170 mm |  |
| Screw M2x5 DIN 7985 | 2 pcs |  |
| Screw M2x6 DIN 965 | 3 pcs |  |
| Screw M2x10 DIN 7985 | 9 pcs |  |
| Washer M2 DIN 125 | 8 pcs |  |
| Nut M2 DIN 934 | 14 pcs |  |
| Screw M3x8 DIN 965 | 2 pcs |  |
| Nut M3 DIN 934 | 2 pcs |  |
| Part 1 - 3D print | 1 pc |  |
| Part 2 - 3D print | 1 pc |  |
| Part 3 - 3D print | 1 pc |  |
| Part 4 - 3D print | 1 pc |  |

## 3D Printing Settings and Material Used

| Parameter | Value |
| :---: | :---: |
| Number of perimeters | 4 |
| Solid top and bottom layers | 5 |
| Infill density | 40% |
| Infill pattern | Gyroid |
| Supports | Tree-like |

Material: coPET black MonoFilament

## Hardware Fasteners Details

| Name | Type/Size | Quantity | Note |
| :--- | :--- | :---: | :---: |
| Screw | M2x5 DIN 7985 | 2 pcs | การติดตั้ง board กับ XS1 connector |
| Nut | M2 DIN 934 | 2 pcs | การติดตั้ง board กับ XS1 connector |
| Screw | M2x10 DIN 7985 | 1 pc | การติดตั้ง XS1 connector retainer |
| Nut | M2 DIN 934 | 1 pc | การติดตั้ง XS1 connector retainer |
| Screw | M3x8 DIN 965 | 2 pcs | การติดตั้ง module BARVINOK-5 RS-485 nano V2.1 |
| Nut | M3 DIN 934 | 2 pcs | การติดตั้ง module BARVINOK-5 RS-485 nano V2.1 |
| Screw | M2x5 DIN 7985 | 4 pcs | การติดตั้ง heatsink |
| Washer | M2 DIN 125 | 4 pcs | การติดตั้ง heatsink |
| Nut | M2 DIN 934 | 4 pcs | การติดตั้ง heatsink |
| Screw | M2x6 DIN 965 | 3 pcs | การติดตั้ง internal strip เข้ากับ module base |
| Nut | M2 DIN 934 | 3 pcs | การติดตั้ง internal strip เข้ากับ module base |
| Screw | M2x10 DIN 7985 | 4 pcs | การติดตั้ง module cover เข้ากับ base |
| Washer | M2 DIN 125 | 4 pcs | การติดตั้ง module cover เข้ากับ base |
| Nut | M2 DIN 934 | 4 pcs | การติดตั้ง module cover เข้ากับ base |

## Wire Usage Details

| Type | Length | Note |
| :--- | :--- | :---: |
| 26 AWG black | 80 mm | XS1 - interface converter |
| 26 AWG green | 80 mm | XS1 - interface converter |
| 26 AWG blue | 80 mm | XS1 - interface converter |
| 26 AWG black | 90 mm | Interface converter - XS2 |
| 26 AWG green | 90 mm | Interface converter - XS2 |
| 26 AWG blue | 90 mm | Interface converter - XS2 |
| 26 AWG black | 90 mm | XS2 - heatsink |

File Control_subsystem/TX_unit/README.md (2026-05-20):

# TX_unit

TX unit ทำหน้าที่เชื่อมต่อ JR-compatible control transmitter module เข้ากับ remote unit hub เพื่อส่งผ่านและแลกเปลี่ยนข้อมูลแบบสองทิศทาง (two-way data exchange) กับ control panel ที่เชื่อมต่ออยู่กับ station control unit รูปภาพแสดงภาพรวมภายนอก (general view) ของ TX unit ขณะติดตั้ง control transmitter เรียบร้อยแล้ว

General view of the TX unit with the control transmitter installed

## Brief Technical Parameters

| Parameter | Value | Note |
|---|---|---|
| Control protocol | CRSF | ผ่าน S.Port |
| Transmission interface | Differential signal ของมาตรฐาน RS-485 | |
| Operating mode | Two-way | Control + telemetry |
| TX unit power supply | จาก remote unit hub | ผ่าน XS2 |
| Control transmitter TX module power supply | 8V | จาก TX unit |
| TX unit output voltage via XS3 connector | 8V | กระแสต่อเนื่องสูงสุด 2A |
| Cooling | Passive | Heatsinks + ช่องระบายอากาศ |
| Shielding | Partial | |

### Interfaces

| Connector | Purpose | Main signals | Note |
|---|---|---|---|
| XS1 | การเชื่อมต่อของ control transmitter | VCC, GND, CRSF (S.Port) | รองรับ JR-compatible control transmitters |
| XS2 | การเชื่อมต่อกับ remote unit hub | +BAT, GND, differential signal ของมาตรฐาน RS-485 | |
| XS3 | ช่องจ่ายไฟออก 8V power output | VCC, GND | การเชื่อมต่อของ high-power control transmitters |

## Circuitry and Functionality of the TX Unit for the Control Transmitter

TX unit รับพลังงานมาจาก remote unit hub โดยแรงดันไฟฟ้าจาก connector XS2 จะถูกส่งไปยัง common ground bus (ซึ่งใช้ copper cooling heatsink ในการระบายความร้อน) และส่งต่อไปยัง voltage converter ซึ่งจะสร้างแรงดัน 8V เพื่อจ่ายไฟให้กับ interface converter และ control transmitter (โปรดตรวจสอบให้แน่ใจว่า TX module ของคุณรองรับแหล่งจ่ายไฟ 8V) นอกจากนี้แรงดันไฟ 8V จะถูกจ่ายออกไปยัง connector XS3 เพื่อรองรับการจ่ายพลังงานให้แก่ high-power control transmitters ที่ต้องการแหล่งจ่ายไฟภายนอก (external power) ทั้งนี้ high-power control transmitter เมื่อรับไฟจาก connector XS3 แล้ว จะต้องไม่มีการเชื่อมต่อทางไฟฟ้ากับขา GND pin ของ connector XS1 เพื่อหลีกเลี่ยงการเกิด ground loop

การแลกเปลี่ยนข้อมูลแบบสองทิศทาง (two-way data exchange) ระหว่าง control transmitter และ control panel จะดำเนินการตามมาตรฐาน RS-485 ผ่าน switching lines ของ ground control station โดยสัญญาณควบคุมผ่าน connector XS2 จะถูกส่งไปยัง interface converter (โมดูล BARVINOK-5 RS-485 nano V2.1) ซึ่งจะแปลง differential signal ของมาตรฐาน RS-485 เป็นสัญญาณโปรโตคอล CRSF ความเร็วสูง แล้วส่งไปยัง control transmitter ผ่านขา S.Port pin ของ connector XS1

การรักษาเสถียรภาพของอุณหภูมิของอุปกรณ์ (temperature modes) ใช้ระบบระบายความร้อนแบบ passive cooling ซึ่งประกอบด้วยช่องระบายอากาศใน housing, silicone thermal pad และ copper heatsink ตัว copper heatsink นี้ทำหน้าที่เป็น common ground (GND) bus ซึ่งช่วยให้สามารถทำหน้าที่เป็นแผงป้องกันเพิ่มเติม (additional shield) เพื่อป้องกันสัญญาณรบกวนทางแม่เหล็กไฟฟ้า (electromagnetic interference) ได้

Schematic diagram of the TX unit for the control transmitter

## List of Necessary Components for Manufacturing One TX Unit

| Name | Quantity | Note |
| :--- | :--- | :---: |
| BARVINOK-5 RS-485 nano V2.1 interface converter module | 1 pc | โมดูลผลิตในยูเครน [ซื้อ BARVINOK-5 RS-485 nano V2.1 จากผู้ผลิต](https://prom.ua/ua/p2693881056-adapter-port-485.html) |
| GUTI ELECTRONICS BEC12S-PRO voltage converter | 1 pc | โมดูลเทียบเท่าของยูเครนเทียบกับ Matek BEC 12S PRO [ซื้อ GUTI ELECTRONICS BEC12S-PRO จากผู้ผลิต](https://prom.ua/ua/p2814749849-otechestvennyj-analog-matek.html) |
| GX12-6 pin panel mount plug (male) | 1 pc | XS2 |
| DC-022 power socket | 1 pc | XS3 |
| Pin header 1x40 2.54mm pitch L=25mm | 3 pins | |
| Pin header 1x40 2.54mm pitch L=15mm | 3 pins | |
| Double-sided prototyping board with 2.54 mm pitch | 30 mm x 70 mm |  |
| Self-adhesive electrical insulating paper 0.2 mm | 30 mm x 30 mm |  |
| Sheet copper 0.8 mm thick | 26 mm x 57 mm |  |
| Silicone thermal pad 2 mm 6W/m.k | 26 mm x 57 mm |  |
| Copper wire 20 AWG with silicone insulation, red | 200 mm |  |
| Copper wire 20 AWG with silicone insulation, black | 250 mm |  |
| Copper wire 26 AWG with silicone insulation, red | 100 mm |  |
| Copper wire 26 AWG with silicone insulation, black | 50 mm |  |
| Copper wire 26 AWG with silicone insulation, green | 80 mm |  |
| Copper wire 26 AWG with silicone insulation, blue | 80 mm |  |
| Screw M3x8 DIN 965 | 2 pcs |  |
| Nut M3 DIN 934 | 2 pcs |  |
| Screw M2x10 DIN 7985 | 12 pcs |  |
| Washer M2 DIN 125 | 12 pcs |  |
| Nut M2 DIN 934 | 12 pcs |  |
| Part 1 - 3D print | 1 pc |  |
| Part 2 - 3D print | 1 pc |  |

## 3D Printing Settings and Material Used

| Parameter | Value |
| :---: | :---: |
| Number of perimeters | 4 |
| Solid top and bottom layers | 5 |
| Infill density | 40% |
| Infill pattern | Gyroid |
| Supports | Tree-like |

Material: coPET black MonoFilament

## XS1 Connector Assembly Process

connector XS1 ถูกประกอบโดยการติดตั้ง long pins และ short pins บน adapter board ที่ตัดมาจาก double-sided prototyping board โดย long pins (L=25mm) จะถูกบัดกรีในลักษณะที่ไม่ยื่นเลย adapter board ออกไปทางด้านของ short pins และใช้สายทองแดงขนาดเล็กเป็นสายเชื่อม (jumpers) ระหว่าง mounting holes ของ prototyping board

XS1 connector assembly process XS1 connector assembly process

short pins (L=15mm) จะถูกบัดกรีในทิศทางตรงกันข้ามกับ long pins

XS1 connector assembly process

ที่ฝั่งของ short pins จะมีการติด self-adhesive electrical insulating paper จำนวน 3 ชั้นลงบน adapter board เพื่อป้องกันการเกิดลัดวงจร (short circuits) จาก contact pads ของ adapter board ไปยัง common ground (GND) polygon ของ interface converter

XS1 connector assembly process

short pins จะถูกบัดกรีเข้ากับ interface converter จากนั้นให้ตัดส่วนเกินของขาแกนกลาง (GND) และขาขวา (S.Port) ออก ส่วนขาซ้าย (VCC) ให้ตัดออกประมาณครึ่งหนึ่ง เพื่อสร้างเป็นจุดรับแรงดันไฟ 8V จาก voltage converter เพื่อนำไปเลี้ยง interface converter และ control transmitter สำหรับ long pins จะถูกเสียบเข้ากับช่องที่ตรงกันใน base ของ unit ระหว่างขั้นตอนการติดตั้ง interface converter

XS1 connector assembly process XS1 connector assembly process

## Hardware Fasteners Details

| Name | Type/Size | Quantity | Note |
| :--- | :--- | :---: | :---: |
| Screw | M3x8 DIN 965 | 2 pcs | การติดตั้ง module BARVINOK-5 RS-485 nano V2.1 |
| Nut | M3 DIN 934 | 2 pcs | การติดตั้ง module BARVINOK-5 RS-485 nano V2.1 |
| Screw | M2x10 DIN 7985 | 6 pcs | การติดตั้ง heatsink |
| Washer | M2 DIN 125 | 6 pcs | การติดตั้ง heatsink |
| Nut | M2 DIN 934 | 6 pcs | การติดตั้ง heatsink |
| Screw | M2x10 DIN 7985 | 6 pcs | การติดตั้ง cover |
| Washer | M2 DIN 125 | 6 pcs | การติดตั้ง cover |
| Nut | M2 DIN 934 | 6 pcs | การติดตั้ง cover |

## Wire Usage Details

| Type | Length | Note |
| :--- | :--- | :---: |
| 20 AWG black | 100 mm | GND bus (cooling heatsink) - XS2 |
| 20 AWG black | 50 mm | GND bus (cooling heatsink) - 12S PRO voltage converter |
| 26 AWG black | 50 mm | GND bus (cooling heatsink) - interface converter |
| 20 AWG black | 100 mm | GND bus (cooling heatsink) - XS3 |
| 26 AWG green | 80 mm | Interface converter - XS2 |
| 26 AWG blue | 80 mm | Interface converter - XS2 |
| 20 AWG red | 100 mm | 12S PRO voltage converter - XS2 |
| 20 AWG red | 100 mm | 12S PRO voltage converter - XS3 |
| 26 AWG red | 100 mm | Interface converter - XS3 |

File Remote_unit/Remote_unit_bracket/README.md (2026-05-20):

# Remote unit bracket

Bracket นี้ได้รับการออกแบบมาสำหรับการติดตั้ง remote unit ของ ground control station บน mast หรือ supporting structures อื่นๆ Bracket ถือเป็นส่วนหนึ่งของ mechanical integration system ของ remote unit การออกแบบนี้มุ่งเน้นไปที่ field operation และการขนย้าย (transportation) ภาพรวมทั่วไปของ remote unit ที่ติดตั้ง antenna เพิ่มเติมบน mast ผ่าน bracket แสดงอยู่ในรูปภาพ

General view of the remote unit with additional antennas on the mast

การออกแบบของ bracket ช่วยรองรับ:
- การติดตั้งหรือใช้งานอย่างรวดเร็ว (quick deployment)
- การยึด remote unit ให้แน่นหนา
- การติดตั้ง rods สำหรับติดตั้ง antenna systems หรืออุปกรณ์อื่นๆ เพิ่มเติม
- การเพิ่มความสูงในการติดตั้ง antenna
- การขยาย antenna configuration ให้เหมาะสมกับสภาพการใช้งาน

## Brief Technical Specifications

| Parameter | Value | Note |
|---|---|---|
| Mounting type | Mast mount | Metal hose clamps |
| Structure type | Modular | |
| Additional antenna and equipment rods | Replaceable | |

## Bill of Materials for One Bracket

| Part Name | Qty | Note |
| :--- | :--- | :---: |
| Screw | M3x35 DIN 7985 | 2 pcs |  |
| Screw | M3x40 DIN 7985 | 4 pcs |  |
| Screw | M3x50 DIN 7985 | 6 pcs |  |
| Washer M3 DIN 9021 | 24 pcs |  |
| Wing nut M3 DIN 315 | 12 pcs |  |
| Hose clamp 28-48 mm DIN3017-1 | 3 pcs |  |
| Aluminum square tube 20x20x2 mm | 500 mm |  |
| Part 1 - 3D printing | 1 pc |  |
| Part 2 - 3D printing | 1 pc |  |
| Part 3 - 3D printing | 1 pc |  |
| Part 4 - 3D printing | 1 pc |  |

## 3D Printing Settings and Material Used

| Parameter | Value |
| :---: | :---: |
| Perimeter count | 4 |
| Top/Bottom solid layers | 5 |
| Infill density | 40% |
| Infill pattern | Gyroid |
| Support | Tree |

Material: coPET black MonoFilament

## Detailed Fastener Requirements

| Part Name | Type/Size | Qty | Note |
| :--- | :--- | :---: | :---: |
| Screw | M3x40 DIN 7985 | 4 pcs | ยึด rods เข้ากับ bracket |
| Washer | M3 DIN 9021 | 8 pcs | ยึด rods เข้ากับ bracket |
| Wing nut | M3 DIN 315 | 4 pcs | ยึด rods เข้ากับ bracket |
| Screw | M3x50 DIN 7985 | 2 pcs | ยึด control antenna bracket |
| Washer | M3 DIN 9021 | 4 pcs | ยึด control antenna bracket |
| Wing nut | M3 DIN 315 | 2 pcs | ยึด control antenna bracket |
| Screw | M3x35 DIN 7985 | 2 pcs | ยึด helical antenna bracket |
| Washer | M3 DIN 9021 | 4 pcs | ยึด helical antenna bracket |
| Wing nut | M3 DIN 315 | 2 pcs | ยึด helical antenna bracket |
| Screw | M3x50 DIN 7985 | 4 pcs | ยึด bracket เข้ากับ hub |
| Washer | M3 DIN 9021 | 8 pcs | ยึด bracket เข้ากับ hub |
| Wing nut | M3 DIN 315 | 4 pcs | ยึด bracket เข้ากับ hub |
| Hose clamp | Hose clamp 28-48 mm DIN3017-1 | 3 pcs | ยึด bracket เข้ากับ mast |

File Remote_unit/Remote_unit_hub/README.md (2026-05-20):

# Remote unit hub

Remote unit hub ทำหน้าที่ในส่วนของ power distribution, signal concentration และการ switching อุปกรณ์ peripheral devices ของ remote unit

General view of the remote unit hub

## Brief Technical Specifications of the Remote Unit Hub

| Parameter | Value | Note |
| :--- | :--- | :---: |
| Input voltage | 6S Li-ion/LiPo battery (Min. 22.2 V, Max. 25.2 V) | จ่ายไฟผ่าน connector XS1 จาก station control unit |
| Power bus | +BAT | ต่อตรงจากแบตเตอรี่ของ station control unit |
| Auxiliary bus | +5 V | แปลงแรงดันโดย DC-DC converter |
| Number of video inputs | 2 | XS3, XS4 |
| Input video signal type | Analog composite (CVBS) | สัญญาณ Analog composite |
| Output video signal type | Analog differential | แปลงและขยายสัญญาณโดย module VA-Do-2/2 จากนั้นส่งสัญญาณผ่าน twisted pair |
| Video input selection | Remote | ควบคุมการ switching จากฝั่ง station control unit |
| VRX control | Supported | ผ่าน ELRS Backpack (video inputs XS3 หรือ XS4) หรือผ่านการเชื่อมต่อแบบสาย (XS3 เท่านั้น) |
| TX interface | Digital (differential) | การส่งข้อมูลของ XS2 ผ่าน twisted pair |
| Power protection | TVS diode | ป้องกันไฟกระชากแบบเหนี่ยวนำ (inductive surges) และแรงดันเกิน (overvoltage) |
| Cooling | Passive | Copper heatsinks + ช่องระบายอากาศ |
| Shielding | Yes | Copper shields |

### Interfaces

| Connector | Application | Main Signals | Note |
| :--- | :--- | :---: | :---: |
| XS1 (GX20-8) | การเชื่อมต่อไปยัง control unit | +BAT, GND, differential lines | การส่งกำลังไฟและการแลกเปลี่ยนสัญญาณ |
| XS2 (GX12-6) | การเชื่อมต่อ TX unit | +BAT, GND, differential line | |
| XS3 (GX12-6) | ช่องสัญญาณ Video input 1, การเชื่อมต่อ VRX1 | +BAT, GND, CVBS, differential line | ช่องสัญญาณ Video input ช่องแรก, รองรับการควบคุมผ่าน twisted pair |
| XS4 (GX12-6) | ช่องสัญญาณ Video input 2, การเชื่อมต่อ VRX2 | +BAT, GND, CVBS | ช่องสัญญาณ Video input สำรอง |

## Schematic Design and Functionality of the Remote Unit Hub

Schematic diagram of the remote unit hub

Remote unit hub รับไฟเลี้ยงผ่าน connector XS1 ซึ่งได้รับแรงดันไฟฟ้าจาก station control unit ที่จ่ายไฟด้วย battery pack แบบ 6S3P Li-ion/LiPo จาก connector XS1 ไฟจะถูกจ่ายไปยัง GND bus และ +BAT bus จากนั้นจะแยกไปยัง connectors XS2, XS3 และ XS4 เพื่อจ่ายไฟให้กับ peripheral devices และ voltage converter ซึ่งทำหน้าที่แปลงแรงดันและจ่ายไปยัง +5V bus เพื่อจ่ายไฟให้กับ video amplifier ทั้งนี้ เพื่อป้องกัน peripheral devices ของ remote unit จาก transient processes ในสายเชื่อมต่อที่เชื่อมไปยัง station control unit (ซึ่งเกิดจากส่วนประกอบที่เป็น inductive) จึงมีการใช้ semiconductor transient voltage suppressor (TVS) รุ่น 1.5KE33A

TX unit จะเชื่อมต่อเข้ากับ connector XS2 และทำการแลกเปลี่ยนข้อมูลระหว่างตัวมันกับ station control unit ผ่าน twisted pair

VRX units หรือแหล่งสัญญาณภาพอื่นๆ จะเชื่อมต่อเข้ากับ connectors XS3 และ XS4 สัญญาณ composite video จาก connectors XS3 และ XS4 จะส่งไปยัง video amplifier ซึ่งจะทำหน้าที่แปลงสัญญาณ composite ให้เป็น differential แล้วส่งผ่าน twisted pair ไปยัง station control unit โดยเมื่อผ่านกระบวนการแปลงสัญญาณกลับ (reverse conversion) ที่ฝั่งสถานีแล้ว สัญญาณภาพจะถูกส่งแยกไปยัง peripheral video devices ต่างๆ ของ station control unit ทั้งนี้ การเลือกช่องสัญญาณ video input ที่ใช้งานอยู่ (XS3 หรือ XS4) จะทำจากฝั่งของ station control unit และสำหรับช่องสัญญาณ video input XS3 จะมี option ในการแลกเปลี่ยนข้อมูลเพิ่มเติมกับ station control unit ผ่าน twisted pair เพื่อรองรับการควบคุมตัวรับสัญญาณวิดีโอจากระยะไกล (remote control)

การควบคุมอุณหภูมิ (temperature stability) ของ video amplifier และ voltage converter ได้รับการดูแลผ่าน copper cooling heatsinks และช่องระบายอากาศบน housing ของ remote unit hub โดย copper heatsinks จะถูกเชื่อมต่อเข้ากับ common ground (GND) bus และเมื่อทำงานร่วมกับ side shield ของ hub board และ shield บน hub cover (ซึ่งเชื่อมต่อเข้ากับ GND bus เช่นกัน) จะช่วยลดสัญญาณรบกวน (parasitic noise/interference) ใน video amplifier ให้เหลือน้อยที่สุด

Remote unit hub มีความหนาแน่นของชิ้นส่วนประกอบค่อนข้างสูงและมีการทำงานกับระดับแรงดันไฟหลายระดับ การประกอบอุปกรณ์ให้ประสบความสำเร็จจำเป็นต้องใช้ทักษะในการอ่าน schematic และประสบการณ์ระดับกลางในการประกอบอุปกรณ์อิเล็กทรอนิกส์ (electronics assembly)

Assembly process of the remote unit hub

## Bill of Materials for One Remote Unit Hub

| Part Name | Qty | Note |
| :--- | :--- | :---: |
| VideoLink VA-Do-2/2 Video Amplifier | 1 pc | module ผลิตในประเทศยูเครน [ซื้อ VideoLink VA-Do-2/2 จากผู้ผลิต](https://sezam.video/shop/videopidsilyuvach-z-simetrichnim-vihodom-aktivniy-balun-videolink-va-do-22/) |
| GUTI ELECTRONICS mBEC12S Voltage Converter | 1 pc | ชิ้นส่วนเทียบเท่าของยูเครนสำหรับ Matek BEC 12S [ซื้อ GUTI ELECTRONICS mBEC12S จากผู้ผลิต](https://prom.ua/ua/p2814749850-otechestvennyj-analog-matek.html) |
| Panel mount plug GX20-8 pin (male) | 1 pc | XS1 |
| Panel mount plug GX12-6 pin (male) | 3 pcs | XS2-XS4 |
| Single-sided copper clad laminate 1.5 mm | 34 mm x 16 mm | Power bus board |
| TVS Diode 1.5KE33A DO201AD | 1 pc | |
| Self-adhesive copper tape (width 50 mm; thickness 0.05 mm) | 156 mm | Shield สำหรับ remote unit hub cover |
| Self-adhesive copper tape (width 8 mm; thickness 0.05 mm) | 286 mm | Side shield ของ hub board |
| Sheet copper 0.8 mm thick | 100 mm x 38 mm | Large heatsink สำหรับ hub board |
| Sheet copper 0.8 mm thick | 30 mm x 19 mm | Voltage converter heatsink |
| Sheet copper 0.8 mm thick | 48 mm x 26 mm | Video amplifier heatsink |
| Silicone thermal pad 1 mm 6W/m.k | 18 mm x 16 mm | การระบายความร้อนจาก voltage converter ไปยัง large heatsink ของ hub board |
| Silicone thermal pad 1.5 mm 6W/m.k | 18 mm x 16 mm | การระบายความร้อนจาก voltage converter ไปยัง heatsink ของตัวเอง |
| Silicone thermal pad 2 mm 6W/m.k | 30 mm x 27 mm - 2 pcs | การระบายความร้อนจาก video amplifier ไปยัง large heatsink ของ hub board |
| Silicone thermal pad 1.5 mm 6W/m.k | 27 mm x 27 mm | การระบายความร้อนจาก video amplifier ไปยัง heatsink ของตัวเอง |
| Copper wire 20 AWG silicone insulated, black | 810 mm | |
| Copper wire 20 AWG silicone insulated, red | 810 mm | |
| Copper wire 26 AWG silicone insulated, black | 120 mm | |
| Copper wire 26 AWG silicone insulated, red | 60 mm | |
| Copper wire 26 AWG silicone insulated, green | 410 mm | |
| Copper wire 26 AWG silicone insulated, blue | 290 mm | |
| Copper wire 28 AWG silicone insulated, black | 680 mm | |
| Coaxial cable RG-316 | 500 mm | |
| Screw M2x6 DIN 7985 | 4 pcs | |
| Screw M2x8 DIN 7985 | 11 pcs | |
| Washer M2 DIN 125 | 15 pcs | |
| Nut M2 DIN 934 | 15 pcs | |
| Screw M3x18 DIN 7985 A2 | 6 pcs | |
| Screw M3x20 DIN 7985 A2 | 5 pcs | |
| Screw M3x25 DIN 965 | 3 pcs | |
| Screw M3x30 DIN 965 | 5 pcs | |
| Screw M3x40 DIN 965 | 3 pcs | |
| Washer M3 DIN 125 | 12 pcs | |
| Washer M3 DIN 9021 | 5 pcs | |
| Nut M3 DIN 934 | 22 pcs | |
| Wing nut M3 DIN 315 | 5 pcs | |
| Part 1 - 3D printing | 1 pc | |
| Part 2 - 3D printing | 1 pc | |
| Part 3 - 3D printing | 1 pc | |
| Part 4 - 3D printing | 1 pc | |

## 3D Printing Settings and Material Used

| Parameter | Value |
| :---: | :---: |
| Perimeter count | 4 |
| Top/Bottom solid layers | 5 |
| Infill density | 40% |
| Infill pattern | Gyroid |
| Support | Tree |

Material: coPET black MonoFilament

## Detailed Fastener Requirements

| Part Name | Type/Size | Qty | Note |
| :--- | :--- | :---: | :---: |
| Screw | M3x25 DIN 965 | 3 pcs | ยึด hub connector block cover |
| Screw | M3x40 DIN 965 | 3 pcs | ยึด hub connector block cover |
| Nut | M3 DIN 934 | 6 pcs | ยึด hub connector block cover |
| Screw | M2x8 DIN 7985 | 3 pcs | ยึด large heatsink เข้ากับ hub board |
| Washer | M2 DIN 125 | 3 pcs | ยึด large heatsink เข้ากับ hub board |
| Nut | M2 DIN 934 | 3 pcs | ยึด large heatsink เข้ากับ hub board |
| Screw | M2x8 DIN 7985 | 4 pcs | ยึด VA-Do-2/2 module heatsink เข้ากับ hub board |
| Washer | M2 DIN 125 | 4 pcs | ยึด VA-Do-2/2 module heatsink เข้ากับ hub board |
| Nut | M2 DIN 934 | 4 pcs | ยึด VA-Do-2/2 module heatsink เข้ากับ hub board |
| Screw | M2x8 DIN 7985 | 4 pcs | ยึด mBEC 12S voltage converter heatsink เข้ากับ hub board |
| Washer | M2 DIN 125 | 4 pcs | ยึด mBEC 12S voltage converter heatsink เข้ากับ hub board |
| Nut | M2 DIN 934 | 4 pcs | ยึด mBEC 12S voltage converter heatsink เข้ากับ hub board |
| Screw | M2x6 DIN 7985 | 4 pcs | ยึด power bus board เข้ากับ hub board |
| Washer | M2 DIN 125 | 4 pcs | ยึด power bus board เข้ากับ hub board |
| Nut | M2 DIN 934 | 4 pcs | ยึด power bus board เข้ากับ hub board |
| Screw | M3x18 DIN 7985 A2 | 6 pcs | ยึด hub board เข้ากับ base |
| Washer | M3 DIN 125 | 12 pcs | ยึด hub board เข้ากับ base (washers 2 ตัวต่อ screw 1 ตัว) |
| Nut | M3 DIN 934 | 6 pcs | ยึด hub board เข้ากับ base |
| Screw | M3x30 DIN 965 | 5 pcs | ยึด hub cover |
| Nut | M3 DIN 934 | 5 pcs | ยึด hub cover |
| Screw | M3x20 DIN 7985 A2 | 5 pcs | การยึดเพิ่มเติมใน hub cover |
| Washer | M3 DIN 9021 | 5 pcs | การยึดเพิ่มเติมใน hub cover |
| Nut | M3 DIN 934 | 5 pcs | การยึดเพิ่มเติมใน hub cover |
| Wing nut | M3 DIN 315 | 5 pcs | การยึดเพิ่มเติมใน hub cover |

## Detailed Wire Consumption

XS1
| Type | Length | Note |
| :--- | :--- | :---: |
| 20 AWG black | 170 mm | XS1 - GND bus ของ hub board |
| 20 AWG red | 170 mm | XS1 - +BAT bus ของ hub board |
| 26 AWG green | 150 mm | XS1 - VA-Do-2/2 |
| 26 AWG blue | 150 mm | XS1 - VA-Do-2/2 |
| 26 AWG green | 60 mm | XS1 - XS2 |
| 26 AWG blue | 60 mm | XS1 - XS2 |
| 26 AWG green | 80 mm | XS1 - XS3 |
| 26 AWG blue | 80 mm | XS1 - XS3 |

XS2
| Type | Length | Note |
| :--- | :--- | :---: |
| 20 AWG black | 190 mm | XS2 - GND bus ของ hub board |
| 20 AWG red | 190 mm | XS2 - +BAT bus ของ hub board |

XS3
| Type | Length | Note |
| :--- | :--- | :---: |
| 20 AWG black | 220 mm | XS3 - GND bus ของ hub board |
| 20 AWG red | 220 mm | XS3 - +BAT bus ของ hub board |
| RG-316 | 250 mm | XS3 - VA-Do-2/2 |

XS4
| Type | Length | Note |
| :--- | :--- | :---: |
| 20 AWG black | 230 mm | XS4 - GND bus ของ hub board |
| 20 AWG red | 230 mm | XS4 - +BAT bus ของ hub board |
| RG-316 | 250 mm | XS3 - VA-Do-2/2 |

mBEC 12S Voltage Converter
| Type | Length | Note |
| :--- | :--- | :---: |
| 26 AWG black | 60 mm | mBEC 12S - GND bus ของ hub board |
| 26 AWG red | 60 mm | mBEC 12S - +BAT bus ของ hub board |
| 26 AWG green | 60 mm | mBEC 12S - +5V bus ของ hub board |

VA-Do-2/2 Module
| Type | Length | Note |
| :--- | :--- | :---: |
| 26 AWG black | 60 mm | VA-Do-2/2 - GND bus ของ hub board |
| 26 AWG green | 60 mm | VA-Do-2/2 - +5V bus ของ hub board |
| 28 AWG black | 50 mm | VA-Do-2/2 - RG-316 cable shield จาก XS3 |
| 28 AWG black | 50 mm | VA-Do-2/2 - RG-316 cable shield จาก XS4 |

Heatsinks and Shields
| Type | Length | Note |
| :--- | :--- | :---: |
| 28 AWG black | 170 mm | Large heatsink ของ hub board - GND bus ของ hub board |
| 28 AWG black | 60 mm | VA-Do-2/2 module heatsink - GND bus ของ hub board |
| 28 AWG black | 60 mm | mBEC 12S voltage converter heatsink - GND bus ของ hub board |
| 28 AWG black | 120 mm | Side shield ของ hub board - GND bus ของ hub board |
| 28 AWG black | 170 mm | Front shield บน hub cover - GND bus ของ hub board |

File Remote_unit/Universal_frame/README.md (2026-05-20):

# Universal frame

Universal frame ได้รับการออกแบบมาสำหรับการติดตั้งและ mechanical integration ของ remote unit hub และ peripheral devices โดย remote unit hub และ peripheral devices ที่ติดตั้งอยู่บน universal frame จะประกอบกันเป็น remote unit ของ ground control station

การออกแบบ frame ช่วยรองรับ:
- การติดตั้ง remote unit hub
- การติดตั้ง TX unit และ VRX units
- การยึดชิ้นส่วนต่างๆ ของระบบเข้าด้วยกันอย่างเป็นหนึ่งเดียว
- การปรับเปลี่ยนสถานะของ remote unit อย่างรวดเร็วระหว่างตำแหน่ง transport และ operational

General view of the remote unit

## Design Features

- โครงสร้างการออกแบบมีลักษณะเป็น modular architecture
- มีพื้นที่รองรับสำหรับการติดตั้ง TX และ VRX units ที่สับเปลี่ยนกันได้
- ทุก module จะถูกยึดด้วยจุดเชื่อมต่อแบบ screw
- การออกแบบมีคุณสมบัติทนทานต่อ mechanical loads และการสั่นสะเทือน (vibrations)

## Transport Position

การจัดตำแหน่ง transport position ของ remote unit ในกล่อง ground control station ประกอบไปด้วย:
- ถอดชิ้นส่วน stand ออก
- ไม่มี VRX unit ใน auxiliary slot
- จัดตำแหน่งยึดของ peripheral devices ให้คงที่

Transport position of the remote unit

## Bill of Materials for One Universal Frame

| Part Name | Qty | Note |
| :--- | :--- | :---: |
| Screw M2x10 DIN 7985 | 12 pcs | ยึด peripheral devices |
| Nut M2 DIN 934 | 12 pcs | ยึด peripheral devices |
| Screw M3x14 DIN 7985 A2 | 2 pcs | ยึด remote unit handle |
| Screw M3x20 DIN 7985 A2 | 2 pcs | ยึด stand |
| Screw M3x30 DIN 965 | 5 pcs | ยึด universal frame เข้ากับ hub |
| Nut M3 DIN 934 | 9 pcs | ยึด universal frame เข้ากับ hub, ยึด stand, ยึด remote unit handle |
| Wing nut M3 DIN 315 | 2 pcs | ยึด stand |
| Self-tapping screw 2x8 DIN 7982 | 2 pcs | ยึด antenna retainer |
| Part 1 - 3D printing | 1 pc |  |
| Part 2 - 3D printing | 1 pc |  |
| Part 3 - 3D printing | 1 pc |  |
| Part 4 - 3D printing | 1 pc |  |

## 3D Printing Settings and Material Used

| Parameter | Value |
| :---: | :---: |
| Perimeter count | 4 |
| Top/Bottom solid layers | 5 |
| Infill density | 40% |
| Infill pattern | Gyroid |
| Support | Tree |

Material: coPET black MonoFilament

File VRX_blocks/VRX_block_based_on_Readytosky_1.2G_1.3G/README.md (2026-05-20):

# VRX block based on Readytosky 1.2G/1.3G

VRX block ที่อิงตาม Readytosky 1.2–1.3 GHz 9CH video receiver คือโมดูลการทำงานที่ติดตั้งบน remote unit และออกแบบมาเพื่อรับสัญญาณ video แบบ analog ในช่วงความถี่ 1.2–1.3 GHz เพื่อส่งต่อไปยังสายสลับสัญญาณ (switching lines) ของ ground station

General view of the 1.2–1.3 GHz VRX unit

## Quick technical specifications of the VRX block based on the Readytosky 1.2–1.3 GHz 9CH video receiver

| Parameter | Value | Note |
|---|---|---|
| Input voltage | แบตเตอรี่ 6S Li-ion/LiPo (Min 22.2V Max 25.2V) | รับพลังงานจาก remote unit hub |
| Frequency range | 1060 - 1380 MHz | 9 channels (1080/1120/1160/1200/1240/1280/1320/1360/1258 MHz) |
| Control | Manual | ผ่าน stock channel selector |
| Output video signal type | Analog composite (CVBS) | |

### Interfaces

| Connector | Purpose | Main signals | Note |
|---|---|---|---|
| XS1 (GX12-6) | การเชื่อมต่อกับ remote unit hub | +BAT, GND, CVBS |  |

## Schematic design and functionality

พลังงานจะถูกจ่ายไปยัง VRX block ผ่าน connector XS1 จากบัส +BAT ของ remote unit hub สัญญาณเอาต์พุต CVBS จาก video receiver จะถูกส่งผ่าน XS1 ไปยังสายสลับสัญญาณ (switching lines) ของ ground control station ส่วนการควบคุมช่องความถี่จะดำเนินการผ่าน stock channel selector ของ video receiver

Schematic diagram of the VRX block based on the Readytosky 1.2–1.3 GHz 9CH video receiver

## List of necessary components for manufacturing one VRX block

| Component Name | Quantity | Note |
| :--- | :--- | :---: |
| Readytosky 1.2–1.3 GHz 9CH video receiver kit | 1 ชิ้น | |
| 90-degree SMA Female to SMA Male elbow adapter | 1 ชิ้น | |
| GX12-6 pin panel mount plug (male) | 1 ชิ้น | XS1 |
| M2x18 screw DIN 7985 | 1 ชิ้น | การยึด video receiver เข้ากับ Part 1 |
| M2 nut DIN 934 | 1 ชิ้น | การยึด video receiver เข้ากับ Part 1 |
| 2x8 self-tapping screw DIN 7982 | 8 ชิ้น | การยึด Part 2 และ Part 3 เข้ากับ Part 1 |
| Part 1 - 3D print | 1 ชิ้น | |
| Part 2 - 3D print | 1 ชิ้น | |
| Part 3 - 3D print | 1 ชิ้น | |
| Part 4 - 3D print | 1 ชิ้น | |

## 3D printing settings and material used

| Parameter | Value |
| :---: | :---: |
| Wall line count (perimeters) | 4 |
| Top and bottom solid layers | 5 |
| Infill density | 40% |
| Infill pattern | Gyroid |
| Supports | Tree-like |

Material: coPET black MonoFilament

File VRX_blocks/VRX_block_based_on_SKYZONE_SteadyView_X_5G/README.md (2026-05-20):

# VRX block based on SKYZONE SteadyView X 5G

VRX block ที่อิงตาม Skyzone SteadyView X 5G video receiver คือโมดูลการทำงานที่ติดตั้งบน remote unit และออกแบบมาเพื่อรับสัญญาณ video แบบ analog ในช่วงความถี่ 4.9–5.9 GHz เพื่อส่งต่อไปยังสายสลับสัญญาณ (switching lines) ของ ground station เพื่อลดการเปล่งแสงของหน้าจอ (screen light emission) สามารถติดตั้ง masking cover ได้ โดยรูปลักษณ์ภายนอกของ VRX block ทั้งแบบที่มีและไม่มี masking cover จะแสดงในภาพถัดไป

General view of the Skyzone SteadyView X 5G VRX unit

## Quick technical specifications of the VRX block based on the Skyzone SteadyView X 5G video receiver

| Parameter | Value | Note |
|---|---|---|
| Input voltage | แบตเตอรี่ 6S Li-ion/LiPo (Min 22.2V Max 25.2V) | รับพลังงานจาก remote unit hub |
| Frequency range | 4.9–5.9 GHz |  |
| Control | Manual or remote | ผ่าน stock control elements หรือ ELRS Backpack |
| Output video signal type | Analog composite (CVBS) | |

### Interfaces

| Connector | Purpose | Main signals | Note |
|---|---|---|---|
| XS1 (GX12-6) | การเชื่อมต่อกับ remote unit hub | +BAT, GND, CVBS |  |

## Schematic design and functionality

พลังงานจะถูกจ่ายไปยัง VRX block ผ่าน connector XS1 จากบัส +BAT ของ remote unit hub สัญญาณเอาต์พุต CVBS จาก video receiver จะถูกส่งผ่าน XS1 ไปยังสายสลับสัญญาณ (switching lines) ของ ground station

Schematic diagram of the VRX block based on the Skyzone SteadyView X 5G video receiver

การเชื่อมต่อระหว่าง video receiver และ connector XS1 จะใช้สายไฟทองแดงที่มีหน้าตัด 26 AWG พร้อมฉนวนซิลิโคน สายไฟสีแดง (+BAT) จะเชื่อมต่อเข้ากับแคโทด (cathode) ของ TVS diode (suppressor), สายไฟสีดำ (GND) เชื่อมต่อเข้ากับขั้วลบของ capacitor, และสายไฟสีเหลือง (CVBS) เชื่อมต่อเข้ากับ pin ที่ 6 ของขั้วต่อบอร์ด RXPORT100 V1.1 ของ Skyzone SteadyView X 5G video receiver

Connecting wires to the RXPORT100 V1.1 board

การควบคุมช่องความถี่จะดำเนินการผ่าน stock control elements ของ video receiver หรือผ่าน ELRS Backpack

## List of necessary components for manufacturing one VRX block

| Component Name | Quantity | Note |
| :--- | :--- | :---: |
| VRX Skyzone SteadyView X 5G video receiver kit | 1 ชิ้น | |
| 90-degree SMA Female to SMA Male elbow adapter | 2 ชิ้น | |
| GX12-6 pin panel mount plug (male) | 1 ชิ้น | XS1 |
| Double-sided acrylic tape 2 mm | 100 mm | การยึด VRX Skyzone SteadyView X 5G เข้ากับ Part 1 |
| 2x8 self-tapping screw DIN 7982 | 8 ชิ้น | การยึด Part 2 และ Part 3 เข้ากับ Part 1 |
| สายไฟทองแดง 26 AWG หุ้มฉนวนซิลิโคน, สีดำ | 150 mm | VRX Skyzone SteadyView X 5G -> XS1 |
| สายไฟทองแดง 26 AWG หุ้มฉนวนซิลิโคน, สีแดง | 150 mm | VRX Skyzone SteadyView X 5G -> XS1 |
| สายไฟทองแดง 26 AWG หุ้มฉนวนซิลิโคน, สีเหลือง | 150 mm | VRX Skyzone SteadyView X 5G -> XS1 |
| Part 1 - 3D print | 1 ชิ้น | |
| Part 2 - 3D print | 1 ชิ้น | |
| Part 3 - 3D print | 1 ชิ้น | |

## 3D printing settings and material used

| Parameter | Value |
| :---: | :---: |
| Wall line count (perimeters) | 4 |
| Top and bottom solid layers | 5 |
| Infill density | 40% |
| Infill pattern | Gyroid |
| Supports | Tree-like |

Material: coPET black MonoFilament

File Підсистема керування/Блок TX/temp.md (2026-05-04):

# Загальний опис

Блок ТХ забезпечує можливість підключення JR-сумісного модуля передавача керування до концентратора виносного блоку для подальшого двостороннього обміну інформацією з пультом керування що підключено до блоку керування станцією. Загальний вигляд блоку ТХ з встановленним передавачем керування показано на картинці.

Загальний вигляд блоку ТХ з встановленним передавачем керування

## Схемотехніка та функціонал блоку ТХ для передавача керування

Живлення блоку ТХ здійснюється від концентратора виносного блоку. Напруга з роз’єму XS2 надходить на шину загального проводу, в якості якої використано мідний радіатор охолодження та на перетворювач наруги, який формує напругу 8В для живлення конвертора інтерфейсів та передавача керування (переконайтеся, що ваш ТХ-модуль підтримує живлення 8В). Напруга 8В додатково виведена на роз’єм XS3 для можливості подачі живлення на потужні передавачі керування які потребують зовнішнього живлення. Зверніть увагу, потужний передавач керування в разі живлення від роз’єму XS3 не повинен мати електричного контакту з піном GND роз’єму XS1 для унеможливлення виникнення земляної петлі.

Двосторонній обмін інформацією між передавачем керування та пультом керування здійснюється за стандартом RS-485 через комутаційні лінії наземної станції. Сигнали керування через роз’єм XS2 надходять на конвертер інтерфейсів (модуль BARVINOK-5 RS-485 nano V2) який перетворює диференційний сигнал стандарту RS-485 в високошвидкісний сигнал протоколу CRSF та через пін S.Port роз’єму XS1 подає його на передавач керування. 

Стабілізацію температурних режимів пристрою забезпечує пасивна система охолодження, що складається з вентиляційних отворів у корпусі, силіконової термопрокладки та мідного радіатора. Мідний радіатор використано в якості шини загального проводу (GND), що дозволяє йому виконувати функцію додаткового екрана для захисту від електромагнітних завад.

Принципова схема блоку ТХ для передавача керування

## Перелік необхідних комплектуючих для виготовлення одного блоку ТХ

| Найменування | Кількість| Примітка |
| :--- | :--- | :---: |
| Модуль конвертора інтерфейсів BARVINOK-5 RS-485 nano V2 | 1 штука | Модуль Українського виробництва |
| Перетворювач напруги GUTI ELECTRONICS BEC12S-PRO | 1 штука | Український аналог Matek BEC 12S PRO |
| Вилка блочна GX12-6 pin (male) | 1 штука | XS2 |
| Роз'єм живлення DC-022 | 1 штука | XS3 |
| Штирьова лінійка 1х40 крок 2.54мм L=25мм | 3 піни | |
| Штирьова лінійка 1х40 крок 2.54мм L=15мм | 3 піни | |
| Макетна плата під пайку двостороння з кроком 2,54 мм | 30 мм х 70 мм |  |
| Самоклеючий електроізоляційний папір 0,2 мм | 30 мм х 30 мм |  |
| Листова мідь товщиною 0.8 мм | 26 мм х 57 мм |  |
| Силіконова термопрокладка 2 мм 6W\m.k | 26 мм х 57 мм |  |
| Провід мідний 20 AWG з силіконовою ізоляцією червоний | 200 мм |  |
| Провід мідний 20 AWG з силіконовою ізоляцією чорний | 250 мм |  |
| Провід мідний 26 AWG з силіконовою ізоляцією червоний | 100 мм |  |
| Провід мідний 26 AWG з силіконовою ізоляцією чорний | 50 мм |  |
| Провід мідний 26 AWG з силіконовою ізоляцією зелений | 80 мм |  |
| Провід мідний 26 AWG з силіконовою ізоляцією синій | 80 мм |  |
| Гвинт M3x8 DIN 965 | 2 штуки |  |
| Гайка M3 DIN 934 | 2 штуки |  |
| Гвинт M2x10 DIN 7985 | 12 штук |  |
| Шайба M2 DIN 125 | 12 штук |  |
| Гайка M2 DIN 934 | 12 штук |  |
| Деталь 1 - 3D друк | 1 штука |  |
| Деталь 2 - 3D друк | 1 штука |  |

## Налаштування 3Д-друку та використаний матеріал

| Параметр | Значення |
| :---: | :---: |
| Кількість периметрів | 4 |
| Суцільних шарів зверху і знизу | 5 |
| Щільність заповнення | 40% |
| Малюнок заповнення | Гіроїд |
| Підтримка | Деревоподібна |

Матеріал coPET black MonoFilament

## Процес виготовлення роз’єму XS1

Роз’єм XS1 утворюється шляхом монтажу довгих та коротких пінів на платі адаптера, що виготовлена з двосторонньої макетної плати під пайку. Довгі піни (L=25мм) паяються таким чином, щоб вони не виходили за межі плати адаптера зі сторони коротких пінів. В якості перемичок між монтажними отворами макетної плати використано тонкий мідний дріт. 

Процес виготовлення роз’єму XS1 Процес виготовлення роз’єму XS1

Короткі піни (L=15мм) паяються в зворотному напрямку відносно довгих пінів.

Процес виготовлення роз’єму XS1

Зі сторони коротких пінів на плату адаптера накладено три шари самоклеючого електроізоляційного паперу для захисту від замикань контактних майданчиків плати адаптера на полігон загального проводу конвертора інтерфейсів.

Процес виготовлення роз’єму XS1

Короткі піни паяються до конвертора інтерфейсів, зайва довжина центрального (GND) та правого (S.Port) піна зрізається, лівий (VCC) пін підрізається приблизно на половину, таким чином формується точка до якої від перетворювача напруги буде підведено 8В для живлення конвертора інтерфейсу та передавача керування. Довгі піни вставляються у відповідні отвори основи блоку при монтажу конвертора інтерфейсів.

Процес виготовлення роз’єму XS1 Процес виготовлення роз’єму XS1

## Деталізація по витраті метизів

| Найменування | Тип/Розмір | Кількість | Примітка |
| :--- | :--- | :---: | :---: |
| Гвинт | M3x8 DIN 965 | 2 штуки | Кріплення модуля BARVINOK-5 RS-485 nano V2 |
| Гайка | M3 DIN 934 | 2 штуки | Кріплення модуля BARVINOK-5 RS-485 nano V2 |
| Гвинт | M2x10 DIN 7985 | 6 штук | Кріплення радіатора |
| Шайба | M2 DIN 125 | 6 штук | Кріплення радіатора |
| Гайка | M2 DIN 934 | 6 штук | Кріплення радіатора |
| Гвинт | M2x10 DIN 7985 | 6 штук | Кріплення кришки |
| Шайба | M2 DIN 125 | 6 штук | Кріплення кришки |
| Гайка | M2 DIN 934 | 6 штук | Кріплення кришки |

## Деталізація по витраті проводу

| Тип | Довжина | Примітка |
| :--- | :--- | :---: |
| 20 AWG чорний	 | 100 мм | Шина GND (радіатор охолодження) - XS2 |
| 20 AWG чорний	 | 50 мм | Шина GND (радіатор охолодження) - перетворювач напруги 12S PRO |
| 26 AWG чорний	 | 50 мм | Шина GND (радіатор охолодження) - конвертор інтерфейсів |
| 20 AWG чорний	 | 100 мм | Шина GND (радіатор охолодження) - XS3 |
| 26 AWG зелений | 80 мм | Конвертор інтерфейсів - XS2 |
| 26 AWG синій | 80 мм | Конвертор інтерфейсів - XS2 |
| 20 AWG червоний	| 100 мм | Перетворювач напруги 12S PRO - XS2 |
| 20 AWG червоний	| 100 мм | Перетворювач напруги 12S PRO - XS3 |
| 26 AWG червоний	| 100 мм | Конвертор інтерфейсів - XS3 |

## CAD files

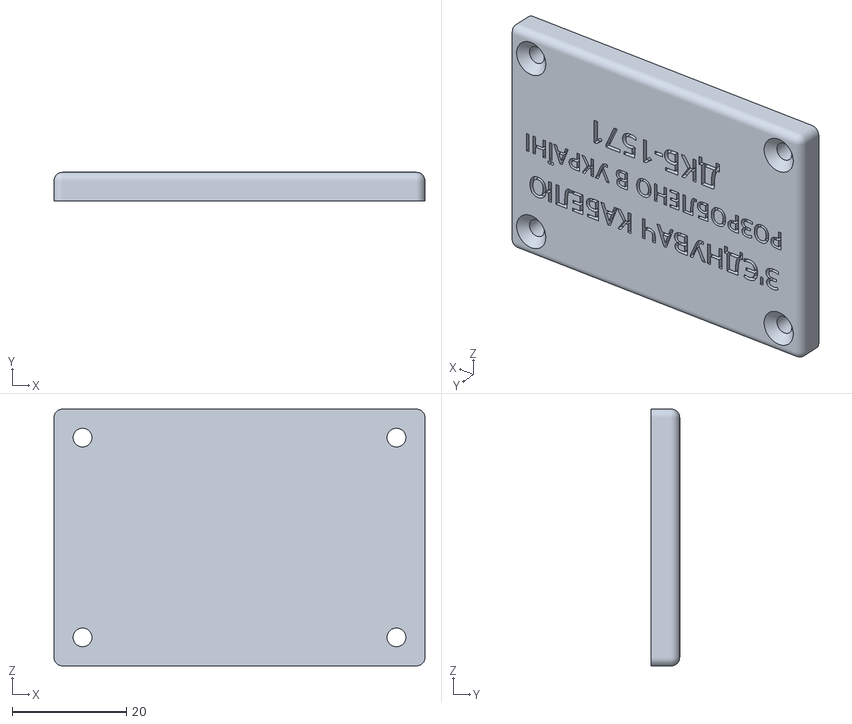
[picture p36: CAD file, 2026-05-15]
Cables/STL/Part_2_connector_housing_cover.STL
65.0 x 5.00 x 45.0

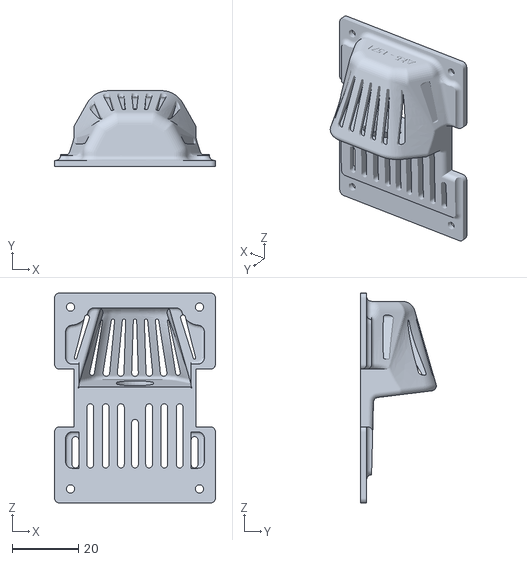
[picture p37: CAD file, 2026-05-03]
Control_subsystem/JR_module_adapter/STL/Part_2_JR_module_cover.STL
48.7 x 22.9 x 63.5

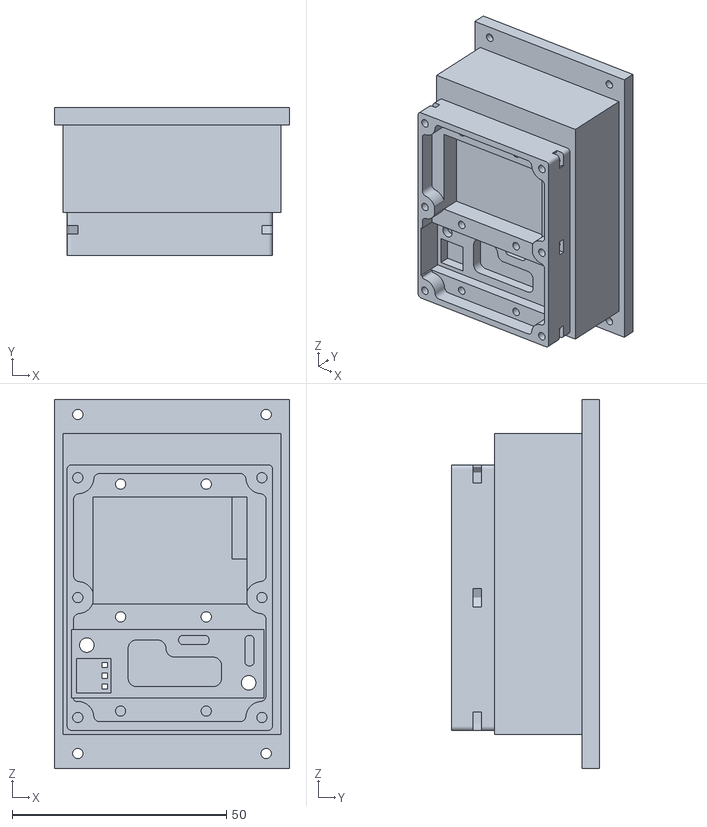
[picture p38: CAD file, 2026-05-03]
Control_subsystem/TX_unit/STL/Part_1_TX_unit_base.STL
55.0 x 34.5 x 86.2

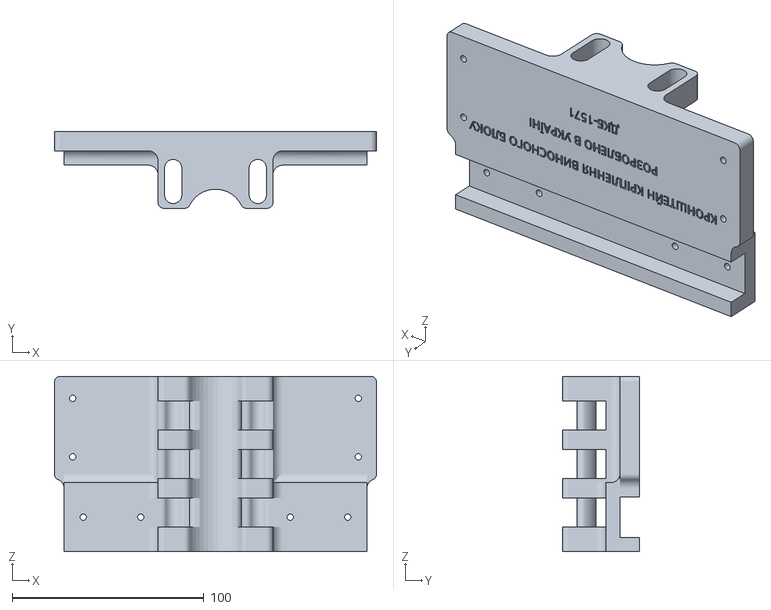
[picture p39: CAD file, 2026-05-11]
Remote_unit/Remote_unit_bracket/STL/Part_1_remote_unit_bracket.STL
168.0 x 40.0 x 91.5

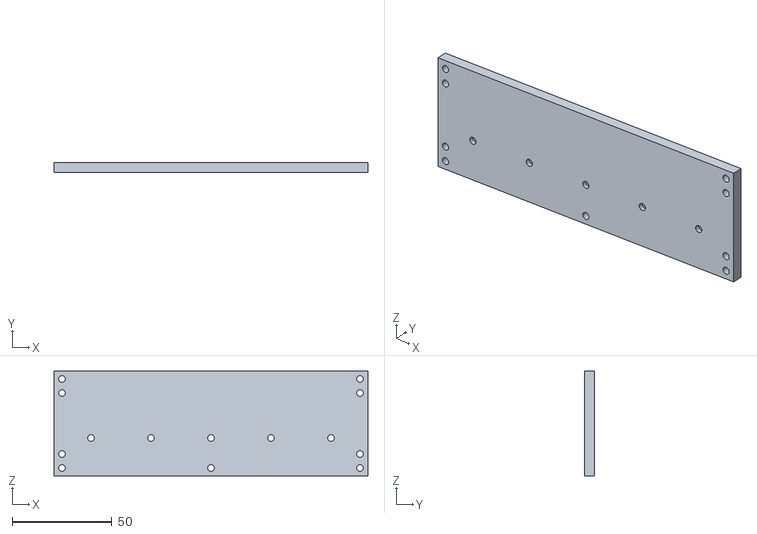
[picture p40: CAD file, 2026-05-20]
Remote_unit/Remote_unit_hub/STL/Part_2_remote_unit_hub_cover.STL
157.0 x 5.00 x 52.5

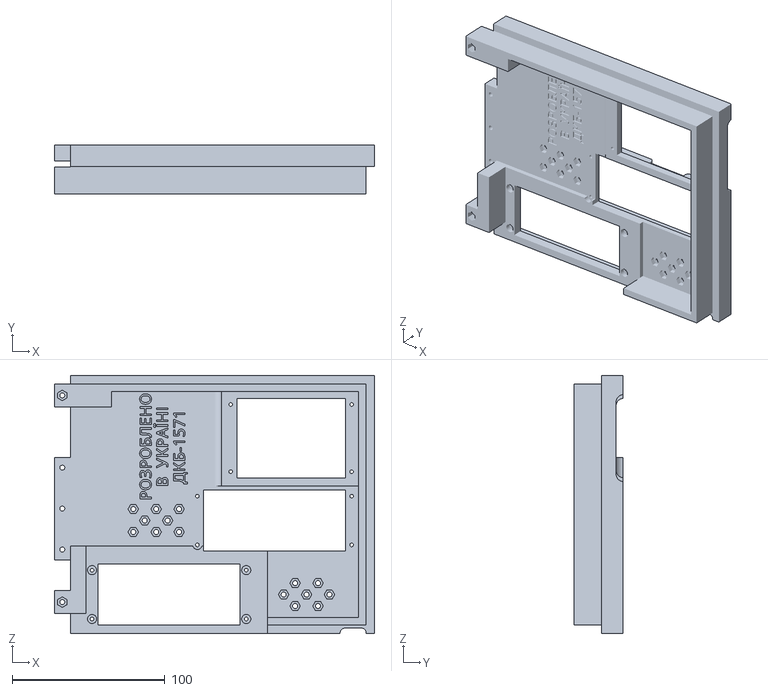
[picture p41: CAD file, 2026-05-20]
Remote_unit/Universal_frame/STL/Part_1_remote_unit_frame.STL
209.6 x 32.0 x 169.0

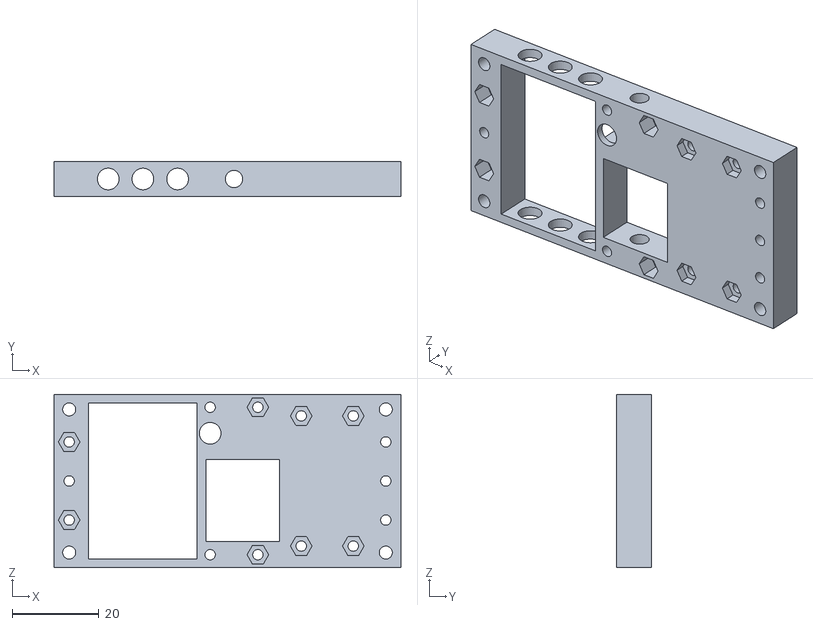
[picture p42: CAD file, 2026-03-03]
Station_control_unit/STL/Part_4_power_distribution_module_housing.STL
80.0 x 8.00 x 40.0

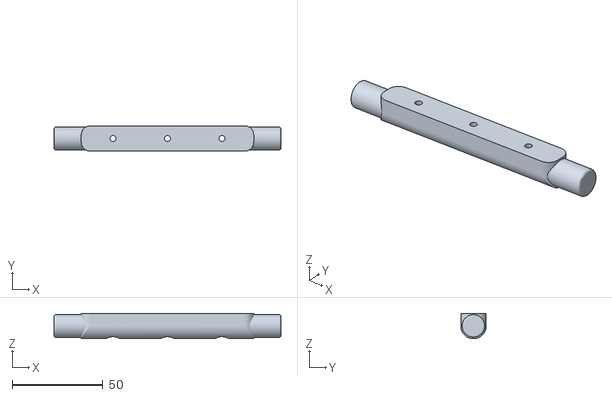
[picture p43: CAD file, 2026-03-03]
Universal_case_and_station_body/STL/Part_8_case_handle_axis.STL
125.0 x 14.0 x 14.0

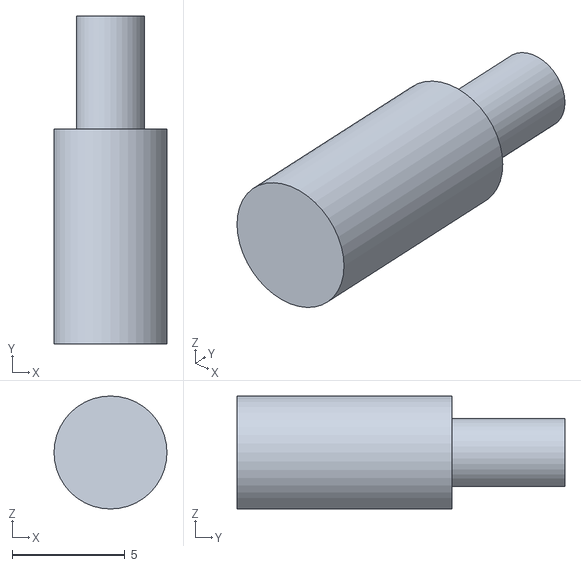
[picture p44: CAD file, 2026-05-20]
VRX_blocks/VRX_block_based_on_Readytosky_1.2G_1.3G/STL/Part_4_channel_switch_rod.STL
5.00 x 14.5 x 5.00

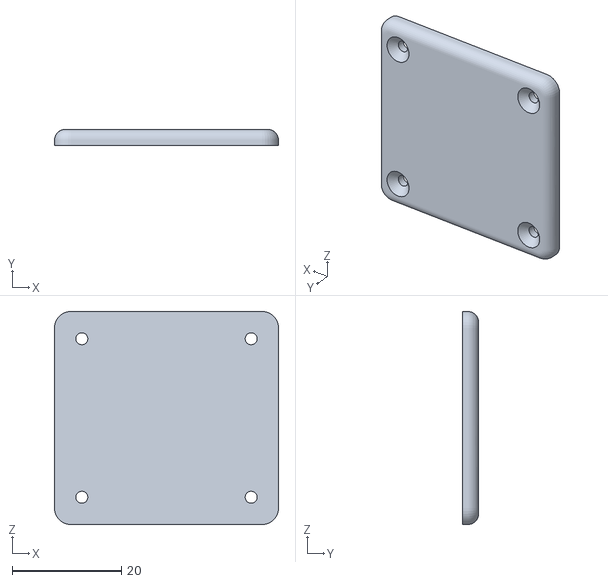
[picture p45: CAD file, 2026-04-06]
VRX_blocks/VRX_block_based_on_SKYZONE_SteadyView_X_5G/STL/Part_2_cover.STL
41.0 x 3.00 x 39.0

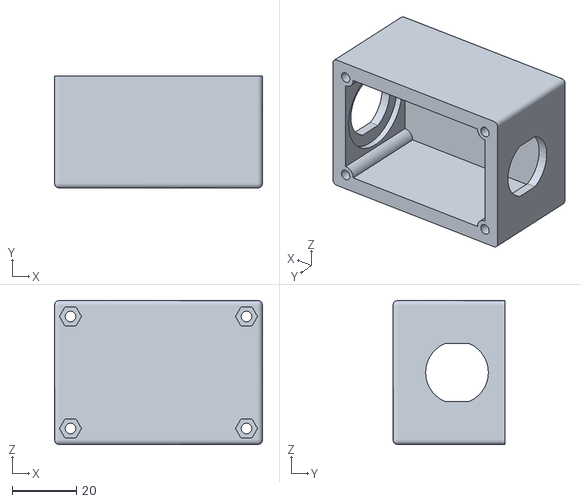
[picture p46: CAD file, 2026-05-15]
Cables/STL/Part_1_connector_housing.STL
65.0 x 35.0 x 45.0

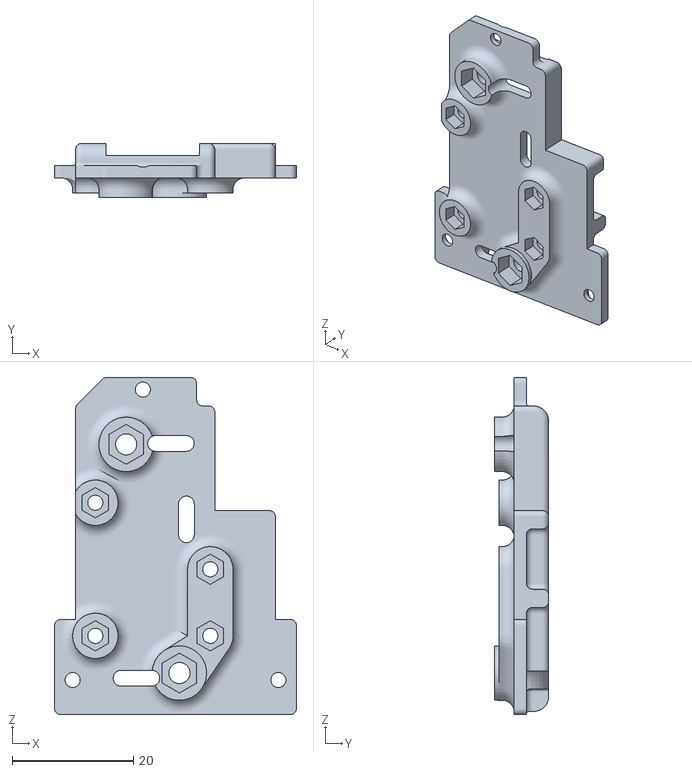
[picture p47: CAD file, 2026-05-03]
Control_subsystem/JR_module_adapter/STL/Part_3_JR_module_inner_bar.STL
40.0 x 9.00 x 55.7

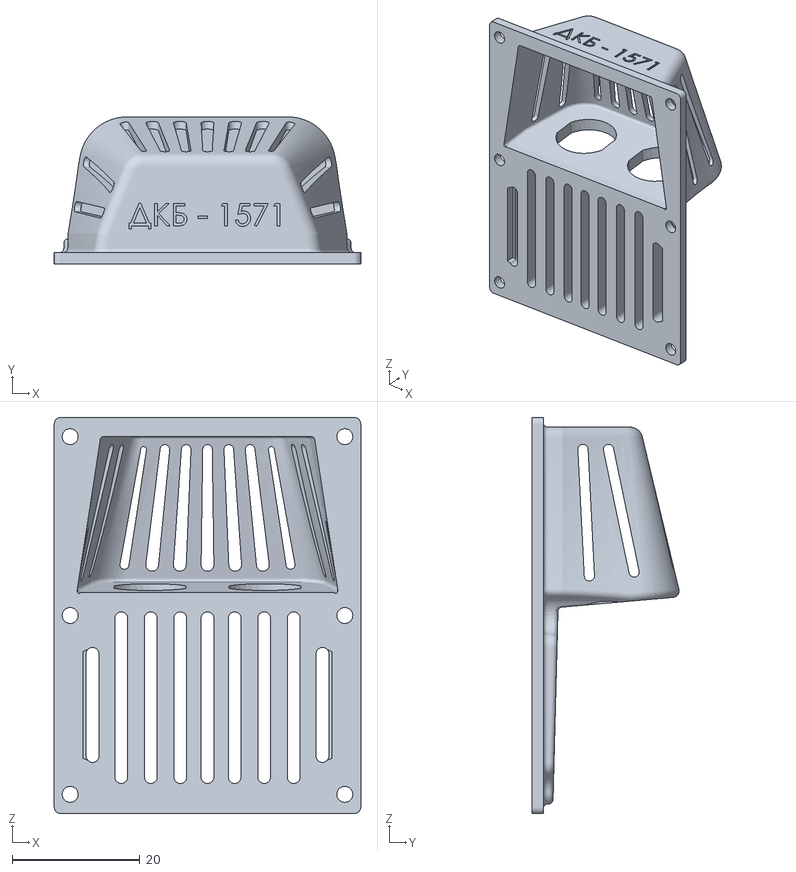
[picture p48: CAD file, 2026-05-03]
Control_subsystem/TX_unit/STL/Part_2_TX_unit_cover.STL
48.0 x 23.1 x 62.0

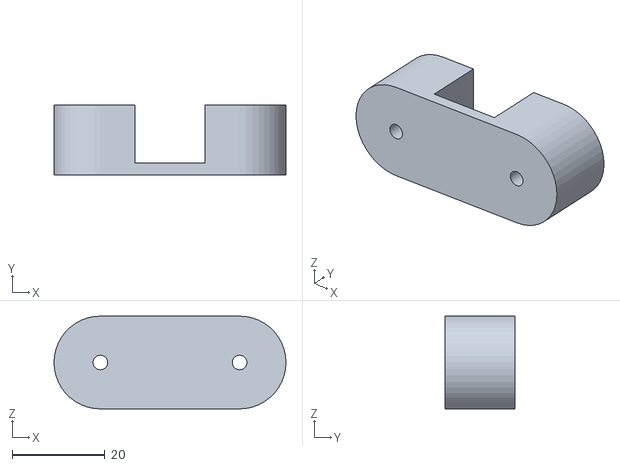
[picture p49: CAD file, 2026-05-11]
Remote_unit/Remote_unit_bracket/STL/Part_3_control_antenna_bracket_base.STL
50.0 x 15.0 x 20.0

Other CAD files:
Remote_unit/Remote_unit_hub/STL/Part_1_remote_unit_hub_base.STL
Remote_unit/Universal_frame/STL/Part_2_stand.STL
Station_control_unit/STL/Part_3_control_unit_back_cover_power_distribution_module_base.STL
Universal_case_and_station_body/STL/Part_4_decorative_monitor_panel_right.STL
Control_subsystem/JR_module_adapter/STL/Part_1_JR_module_base.STL
Control_subsystem/JR_module_adapter/STL/Part_4_connector_holder.STL
Remote_unit/Remote_unit_bracket/STL/Part_2_helical_antenna_bracket.STL
Remote_unit/Remote_unit_bracket/STL/Part_4_control_antenna_bracket_top.STL
Remote_unit/Remote_unit_hub/STL/Part_3_hub_connector_block_cover.STL
Remote_unit/Remote_unit_hub/STL/Part_4_hub_pcb.STL
Remote_unit/Universal_frame/STL/Part_3_remote_unit_handle.STL
Remote_unit/Universal_frame/STL/Part_4_antenna_holder.STL
Station_control_unit/STL/Part_1_control_unit_base.STL
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

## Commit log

2026-02-18 Uploading .STL files
    Updated versions of files have been uploaded
    [Деталь 1 кришка кейсу верхня ліва.STL, Деталь 2 кришка кейсу верхня права.STL, Деталь 5 основа кейсу нижня ліва.STL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]
2026-02-28 New version files added
    During the assembly of the test sample, it was discovered that certain changes needed to be made
    [Деталь 5 основа кейсу нижня ліва.STL, Деталь 6 основа кейсу нижня права.STL]
2026-02-28 Delete Універсальний кейс та корпус станції directory
    Зміна структури директорій
    [Деталь 1 кришка кейсу верхня ліва.STL, Деталь 2 кришка кейсу верхня права.STL, Деталь 3 декоративна панель монітора ліва.STL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]
2026-05-20 Translate repository contents, filenames, and links to English
    [Part_1_JR_module_base.STL, Part_1_TX_unit_base.STL, Part_1_block_base.STL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]
2026-05-20 Update ground station architecture diagram with the English version
